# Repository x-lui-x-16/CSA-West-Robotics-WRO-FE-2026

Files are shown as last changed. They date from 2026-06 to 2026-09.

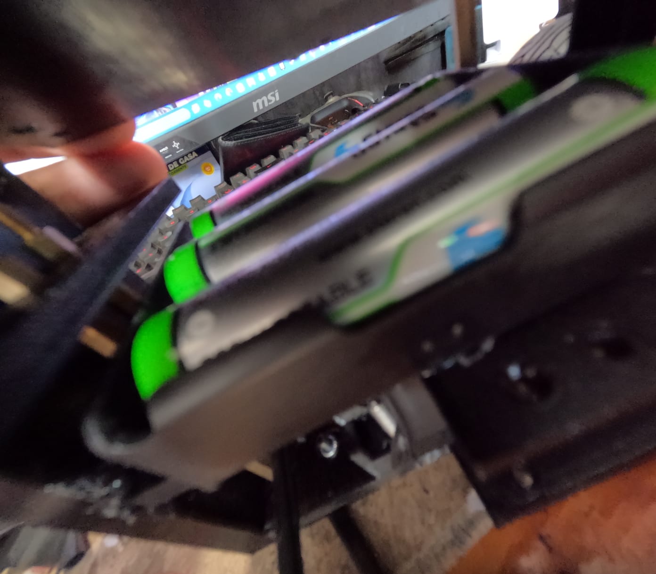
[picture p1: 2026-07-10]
electromechanical-components/battery/battery pic 3.jpeg

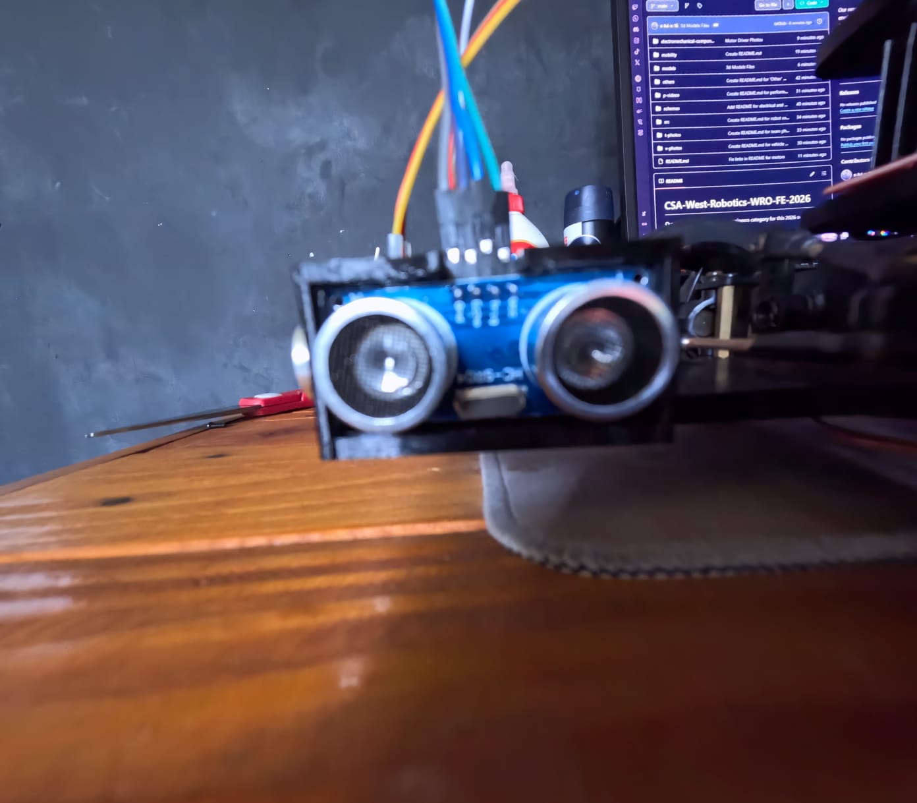
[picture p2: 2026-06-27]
electromechanical-components/ultrasonic-sensors/ultrasonic sensors pic 2.jpeg

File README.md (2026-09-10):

## 👋 Introduction
For the WRO Future Engineers challenge, we built an autonomous robot that combines computer vision, distance sensing, and precise motion control. A **Pixy2 camera** detects colored markers along the track: green means turn left, red means turn right. Three **HC-SR04 ultrasonic sensors** on the front give the robot environmental awareness, letting it detect the front wall and nearby obstacles. Together, vision and ultrasonic sensing let the robot follow navigation rules while avoiding collisions, reliably and adaptively.

## 👥 Our Team
<center>27fb941c-3ae1-49fe-bac8-5fe324d17b53</center>

| Photo | Name | Role - Decription |
|:---:|---|---|
| WhatsApp Image 2026-09-08 at 9 08 41 AM | Ernesto Victoria | Coach - 	Guides the team's strategy, training and overall project direction. |
| WhatsApp Image 2026-08-29 at 6 13 13 PM | Zaory Puga | Programmer - 	Develops and refines the robot's navigation and control code. |
| WhatsApp Image 2026-08-29 at 6 13 14 PM | Dereck Cisneros | Mechanic - 	Designs and builds the robot's chassis and mechanical systems. |
| WhatsApp Image 2026-08-29 at 6 13 13 PM (1) | Luis Hidalgo | Mechanic & Programmer — Team Captain - Leads the team, combining mechanical design with programming to integrate the robot's systems. |

## 🛠️ Building Instructions
- Chassis: mostly 3D-printed, with some supports from the [YFROBOT Kit Chassis](https://yfrobot.com/products/steering-gear-robot).
- 3D Models: [printable STL files](models/)
- Electronics: [circuit diagrams](schemes/)
- Code: [Arduino source code](src/)

## 🚗 Mobility
Our robot uses **Ackermann steering**, the same geometry found in real cars, steering only the front wheels while the rear wheels drive. An **MG996R servo** actuates the steering linkage based on decisions from the **Arduino Mega 2560 R3**. Propulsion comes from a **LEGO EV3 Large Motor** on a rigid rear axle. This separation of steering and driving reduces wheel slip, improves traction, and gives smoother, more predictable handling — important for accurate obstacle avoidance and parking.
- [RWD System](mobility/rwd-system/) · [Steering Mechanism](mobility/steering-mechanism/)

## 🎯 Strategy
- **Color detection:** the Pixy2 cam identifies green/red markers; green → turn left, right → turn right.
- **Turn triggering:** the robot drives straight until the front sensor detects the wall is close; side sensors then decide turn direction.
- **Color algorithm & obstacle-avoidance routine:** to be documented in phase 2.

## 💻 Code Overview
The robot: waits for a start button → drives forward with the steering servo held straight (90°), with no wall-following correction → watches the front sensor to detect the front wall → checks side distances to decide turn direction → executes a timed 90° turn via the servo → counts turns → repeats until the required laps are done → makes a final short move and stops.

**Key logic:**
- A simple **state machine** (`DRIVE_STRAIGHT`, `TURNING_LEFT`, `TURNING_RIGHT`, `FINISHED`) organizes behavior.
- The robot drives straight until the front sensor reads a distance below `FRONT_TURN_TRIGGER_MM`, signaling that the front wall is close.
- Turns are currently **time-based** (`turn90TimeMs`), which is simple but can vary with battery level, traction, and surface — a future version could add wheel encoders or an IMU for more precise turning.
- Tunable parameters: servo angles, `baseSpeedPercent`, `turnSpeedPercent`, `turn90TimeMs`, `FRONT_TURN_TRIGGER_MM`, `TURN_RATIO`, final-stop timing.

## ⚙️ Electromechanical Components
- **Power:** 3S 18650 Li-ion battery pack (three 3.7V, 2800 mAh 18650 cells in series) → L298N (+12V/GND) → onboard 5V regulator powers a breadboard distributing to Arduino, sensors, etc. Includes a power switch and a start button.
- **Controller:** Arduino Mega 2560 R3 — processes sensor data and controls the motors.
- **Vision:** Pixy2 Camera detects red/green markers and reports to the Arduino for turn decisions. *(Communication protocol & detection algorithm to be documented in phase 2.)*
- **Ultrasonic sensors:** 3× HC-SR04 (left, center, right), ~2–400 cm range, ~3 mm accuracy — used for obstacle detection and front-wall detection.
- **Drive:** LEGO EV3 Large Motor, with a built-in rotation sensor.
- **Steering:** MG996R digital servo (4.8–7.2V, PWM control).
- **Motor driver:** L298N Dual H-Bridge — also supplies regulated 5V.
- **Chassis:** custom-designed, mostly 3D-printed (4 wheels, 8 supports, mounting screws), optimizing component placement and easy maintenance.

### 🔋 Power System
The robot is powered by a 3-cell (3S) 18650 lithium battery pack, which supplies the energy required for all electronic and mechanical components. The battery holder includes an integrated power switch, allowing the entire robot to be turned on safely before each run.

The battery pack is connected directly to the L298N motor driver through its +12V and GND terminals. The onboard 5V regulator of the L298N is then used to power a breadboard, which distributes power to the Arduino, sensors, and the remaining electronic devices.

To improve usability during competitions, the robot also includes a push button that starts the autonomous program after the robot has been powered on.

[📷 Power System Image](electromechanical-components/battery/)

### 🧠 Main Controller

The main controller of the robot is an Arduino Mega 2560 R3, which acts as the central processing unit of the entire system. It receives information from the vision system and ultrasonic sensors, processes all navigation decisions, and controls the motors accordingly.

Its compact size, processing capability, and reliable I/O communication make it an excellent choice for autonomous robotics applications.

[📷 Arduino Mega 2560 R3 Image](electromechanical-components/arduino/)

### 👁️ Vision System

The robot uses a Pixy2 Camera to detect the colored obstacle markers placed around the track.

A custom vision algorithm allows the camera to distinguish between red and green objects. Once a color is identified, the corresponding information is transmitted to the Arduino Mega 2560 R3, which decides whether the robot should turn left or right according to the competition rules.

#### Communication Protocol:

The communication protocol will be developed and documented in the second phase of the challenge.  

This section will later describe how the robot exchanges information between the arduino and the Pixy2 Camera, the structure of the transmitted data, and how that communication supports the overall project workflow.

#### Detection Algorithm:

The detection algorithm will also be addressed in the second phase of the challenge.  

At that stage, this section will explain how camera data is processed to identify relevant conditions, events, or targets, and how those detections are integrated into the robot’s navigation and decision-making logic.

[📷 Pixy2 Camera Image](electromechanical-components/pixy2/)

### 📏 Ultrasonic Sensors

Three HC-SR04 ultrasonic sensors are mounted across the front of the robot.

These sensors continuously measure the distance between the robot and nearby walls or obstacles, allowing the robot to navigate safely through the track.

Each HC-SR04 sensor provides non-contact distance measurements from approximately 2 cm to 400 cm, with an accuracy of up to 3 mm.

The sensor arrangement consists of:
- Left ultrasonic sensor
- Center ultrasonic sensor
- Right ultrasonic sensor

Together, these sensors provide the robot with a wider field of view, enabling more accurate obstacle avoidance and wall-following behavior.

[📷 Ultrasonic Sensors](electromechanical-components/ultrasonic-sensors/)

### ⚙️ Drive System

#### DC Motor

The robot is driven by the EV3 Large Motor.

These motors provide a good balance between speed and torque, allowing smooth movement while maintaining enough power for acceleration, turning, and obstacle avoidance during the competition.

[📷 DC Motor](electromechanical-components/motors/dc-motor/)

#### Servo Motor

The robot uses an MG996R high-torque servo motor to control the steering mechanism of the front wheels. Unlike differential-drive robots, our vehicle follows an Ackermann-inspired steering configuration, allowing it to perform smoother and more realistic turns while maintaining stability throughout the course.

The Arduino Mega 2560 R3 continuously calculates the desired steering angle using data from the Pixy2 camera and the ultrasonic sensors. Based on this information, the servo precisely adjusts the front wheels, enabling the robot to navigate around obstacles, follow the track, and execute accurate parking maneuvers.

The MG996R was selected because of its high torque, fast response, and reliable performance, making it well suited for the steering demands of the WRO Future Engineers challenge.

Specifications:
- Model: MG996R
- Operating Voltage: 4.8–7.2 V
- Control Signal: PWM
- Type: High-Torque Digital Servo

[📷 Servo Motor](electromechanical-components/motors/servo-motor/)

### 🎮 Motor Driver

Motor control is performed using an L298N Dual H-Bridge Motor Driver.

The driver receives movement commands from the Arduino Mega 2560 R3 and regulates the motors accordingly. Besides driving the motors, the L298N also provides a regulated 5V output, which is used to power the breadboard and the robot's low-voltage electronics.

The L298N was selected because it is reliable, easy to integrate, and widely used in educational and robotics projects.

[📷 Motor Driver](electromechanical-components/motor-driver/)

### 🏗️ Mechanical Structure

The chassis was entirely designed by our team and manufactured primarily using 3D printing.

Almost every structural component of the robot is custom-made, allowing us to optimize the placement of electronics, reduce weight, simplify maintenance, and adapt the robot specifically for the WRO Future Engineers challenge.

Only the structural supports and steering mechanism were not 3D printed.

The robot includes:
- 4 wheels
- 8 structural supports
- Structural mounting screws
- Custom 3D-printed chassis

This modular design allows individual components to be replaced quickly without rebuilding the entire robot.

### 🔌 Wiring Diagram

The electrical connections between all components are summarized in the wiring diagram below.
FE-2026 V3 Wiring Diagram
### 📸 Component Gallery

The following folder shows images of all the main electromechanical components used in the robot.
- [Electromechanical Components](electromechanical-components/)
📸 [Component gallery](electromechanical-components/)

## ⚡ Power Management

The robot is powered by a **3S 18650 lithium battery pack** pack (three 3.7V, 2800 mAh cells in series), which supplies the main power source for the entire system. The battery output is connected directly to the **L298N motor driver** through its **+12V** and **GND** terminals. This allows the driver to power the DC motors while simultaneously providing a regulated **5V output**.

The regulated **5V** and **GND** outputs from the L298N are connected to a **breadboard**, which acts as the central power distribution point for the low-voltage electronics. From there, power is supplied to the **Arduino Mega 2560 R3**, the **Pixy2 camera**, the **MG996R steering servo**, and the **HC-SR04 ultrasonic sensors**.

To improve safety and usability, the robot includes a **main power switch** that disconnects the battery from the entire electrical system when not in use. Additionally, a dedicated **start button** allows the robot to remain powered while delaying the execution of the autonomous program until the official start signal is given.

This power management architecture simplifies wiring, centralizes power distribution, and ensures that all electronic components receive a stable supply voltage throughout the robot's operation.

## 🫶🏽 Acknowledgements
- **Colegio San Agustín La Chorrera** — guidance and workspace.
- **Gabriel Rodríguez (Banistmo)** — technical guidance, programming support and feedback.
- **TekBot Lab** — help with robot design and technical feedback.

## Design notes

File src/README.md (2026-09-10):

# 💻 Source Code
This directory contains all the software developed for the robot.

The code is written for the Arduino Mega 2560 R3 and manages all the robot's autonomous behavior, including sensor processing, decision-making, and motor control.

## 📌 Features
- Real-time sensor data processing
- Color detection integration (Pixy2 camera)
- Obstacle detection using ultrasonic sensors
- Steering control using servo motor
- Motor control via L298N driver
- Autonomous navigation logic

## ⚙️ System Behavior
The robot continuously reads sensor inputs, processes environmental data, and executes movement decisions in real time to complete the WRO challenge autonomously.

## 🧠 Architecture
The software is structured to ensure modularity, making it easier to test, debug, and improve individual subsystems.

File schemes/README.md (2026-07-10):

# 🗺️ Schemes
This directory contains all electrical and wiring diagrams used in the robot.

These schemes document how each component is connected, ensuring clarity in the system architecture and facilitating debugging, assembly, and maintenance.

## 📌 Contents
- Wiring diagrams of the robot
- Wiring Explanation detailed

## ⚡ Overview
The diagrams illustrate how power and data flow between the Arduino Nano 33 IoT, Pixy2 camera, ultrasonic sensors, motor driver, and steering system.

These schematics are essential for understanding the robot’s electrical design.

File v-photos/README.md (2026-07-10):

# 🤖🚗 Vehicle Photos
This directory contains detailed images of the robot.

## 📌 Contents
- Full robot assembly photos
- Front, side, and top views

## 🔍 Purpose
These images help illustrate the mechanical design, component layout, and overall structure of the robot, providing a clear understanding of the system architecture.

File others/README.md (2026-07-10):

# 📁 Other
This folder contains miscellaneous files related to the project.

At the moment, this directory is kept empty or used for temporary files that are not part of the main system structure.

## 📌 Purpose
This space is reserved for:
- Experimental files
- Backup resources
- Temporary documentation
- Non-critical assets

## 🧹 Status
Currently, no essential files are stored in this directory.

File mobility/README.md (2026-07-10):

# 🚗 Mobility
This section shows the robot’s mobility system and steers.

The robot is designed with a separated propulsion and steering architecture to ensure smooth and precise movement throughout the WRO Future Engineers challenge.

## 📌 Contents
- Ackermann steering system
- Rear-wheel drive configuration

## ⚙️ System Overview
The robot uses a **rear-wheel drive system** powered by a Geartisan 12V DC motor, which provides consistent forward motion.

Steering is handled by an **MG996R servo motor**, which controls an Ackermann-style linkage connected to the front wheels. This setup allows for smooth turning behavior and reduces wheel slip during direction changes.

The combination of these two systems ensures stable navigation, accurate turning radius control, and reliable performance in dynamic track conditions.

## 🔍 Purpose
The mobility system is designed to replicate realistic vehicle behavior, improving stability and control while allowing the robot to execute precise maneuvers such as obstacle avoidance and parking.

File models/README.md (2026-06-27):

# 🧊 Models
This directory contains all the 3D models used in the robot.

All files stored here correspond to parts designed for 3D printing and assembly of the robot structure. These models were created specifically for this project to ensure proper fit, modularity, and mechanical efficiency.

## 📌 Contents
- 3D printable robot parts
- Sensor and electronics mounts

## 🛠️ Purpose
The main purpose of these models is to provide a complete and modular mechanical structure for the robot, allowing easy assembly, replacement, and improvement of components during development and testing.

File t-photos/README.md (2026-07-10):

# 📸 Team Photos
This directory contains the official team photographs for the WRO Future Engineers competition.

## 📌 Contents
- Official team presentation photos
- Group photos of team members
- Competition preparation images

## 🏆 Purpose
These images are used for documentation and team identification during the competition and in the official GitHub repository.

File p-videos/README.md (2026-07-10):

# 📹 Performance Videos
This directory contains videos of the robot performing in different competition scenarios.

## 📌 Contents
- Autonomous navigation tests
- Obstacle detection demonstrations
- Full challenge runs
- System validation recordings

## 🎯 Purpose
These videos demonstrate the robot’s performance, reliability, and ability to complete the required tasks under competition conditions.

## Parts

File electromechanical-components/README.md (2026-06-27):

# ⚙️ Electromechanical Components
This directory contains all the main mechanical and electronic components used in the robot.

## 📌 Contents
- 🔋 Power system 
- 🧠 Main controller 
- 👁️ Vision system 
- 📏 Ultrasonic sensors 
- ⚙️ Drive system 
- 🎮 Motor driver 

## 🔍 Purpose
These components form the complete electromechanical architecture of the robot, integrating power, control, sensing, and actuation systems into a single autonomous platform.

This folder helps document the hardware design and provides a clear overview of how each subsystem contributes to the robot’s overall functionality in the WRO Future Engineers challenge.

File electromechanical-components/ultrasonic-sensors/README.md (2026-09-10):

# 📏 Ultrasonic Sensors (HC-SR04)
Three HC-SR04 ultrasonic sensors are mounted on the front of the robot: left, center, and right. Each one measures distance in a range of roughly 2–400 cm with about 3 mm accuracy.

The center sensor detects when the robot is approaching the front wall, triggering a turn, while the left and right sensors are compared to decide the turn direction.

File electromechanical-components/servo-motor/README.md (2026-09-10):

# 🕹️ Steering Servo (MG996R)
The MG996R is a high-torque digital servo that controls the robot's Ackermann steering mechanism. Based on distance readings and navigation decisions from the Arduino, it adjusts the angle of the front wheels to keep the robot on track and execute turns.

It operates at 4.8–7.2V and is controlled via a standard PWM signal from the Arduino.

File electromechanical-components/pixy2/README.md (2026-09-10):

# 👁️ Pixy2 Camera
The Pixy2 Camera is the robot's vision system. It detects colored markers placed along the track and identifies whether they are green or red. This information is sent to the Arduino, which decides whether the robot should turn left (green) or right (red).

The communication protocol and detection algorithm will be documented in more detail in the next development phase.

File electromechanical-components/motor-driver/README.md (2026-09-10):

# 🎮 Motor Driver (L298N)
The L298N Dual H-Bridge Motor Driver receives movement commands from the Arduino and controls the drive motor's speed and direction. It also provides a regulated 5V output, which powers the breadboard and the robot's low-voltage electronics (Arduino, sensors, servo).

It was selected for being reliable, easy to wire, and widely supported in educational robotics projects.

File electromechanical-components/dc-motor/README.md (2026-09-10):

# ⚙️ Drive Motor
Propulsion is provided by a LEGO EV3 Large Motor, connected to the rigid rear axle. It includes a built-in rotation sensor, which could be used in future versions to measure distance traveled more precisely than the current time-based approach.

This motor was chosen for its reliable torque and smooth speed control, providing consistent forward motion throughout the track.

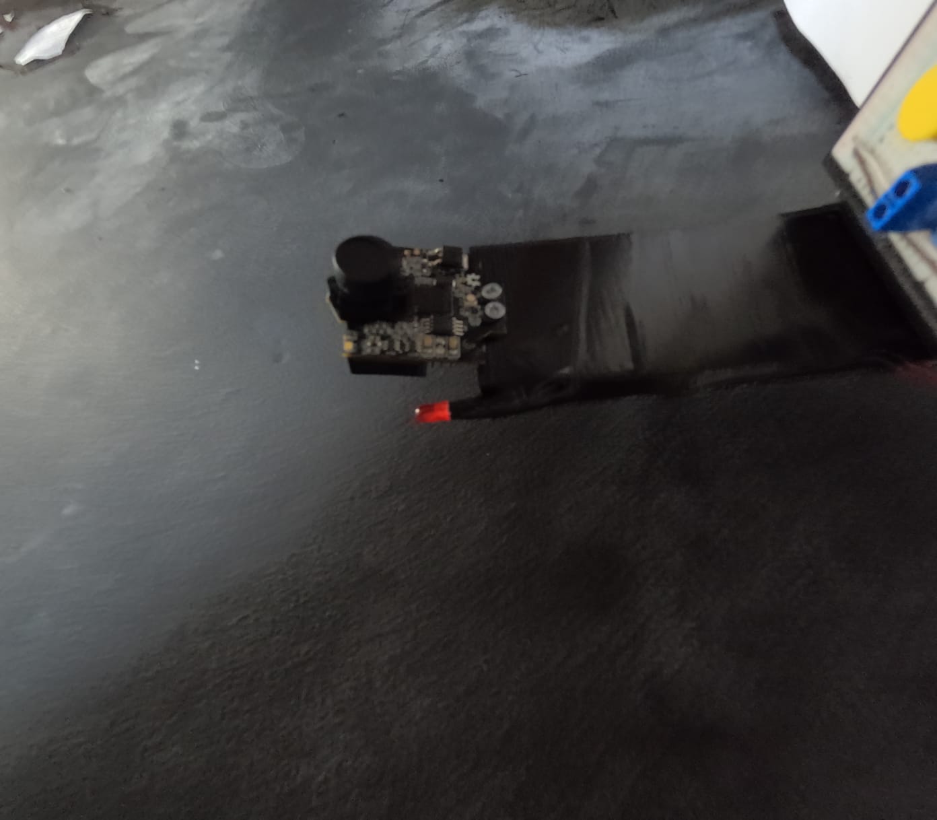
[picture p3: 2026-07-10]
electromechanical-components/pixy2/pixy2 pic 1.jpeg

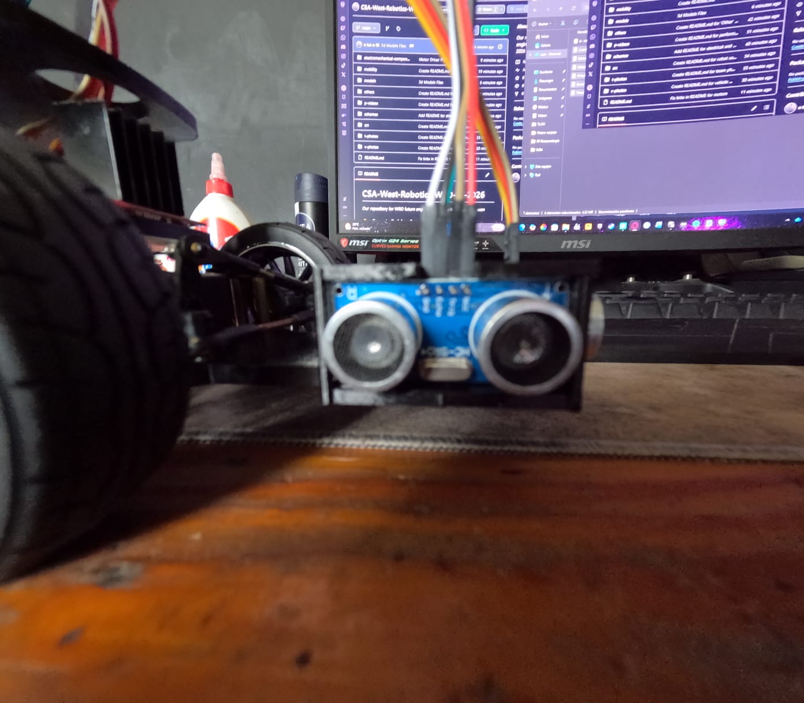
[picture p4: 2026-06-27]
electromechanical-components/ultrasonic-sensors/ultrasonic sensors pic 3.jpeg

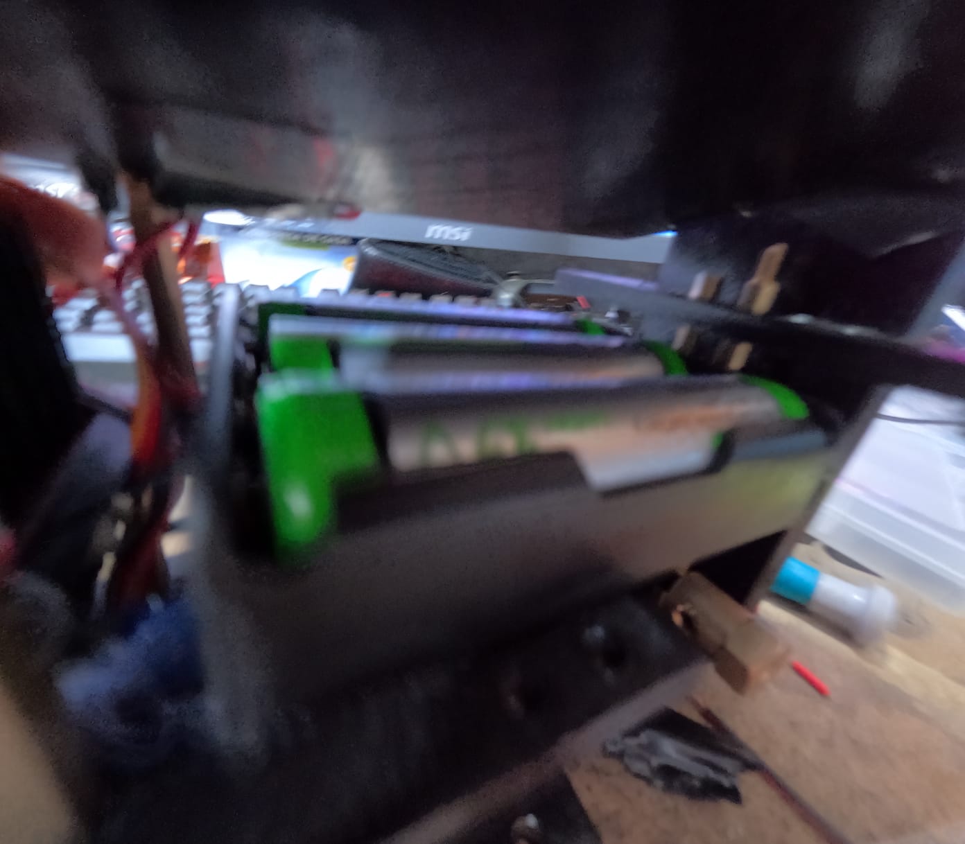
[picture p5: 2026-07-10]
electromechanical-components/battery/battery pic 2.jpeg

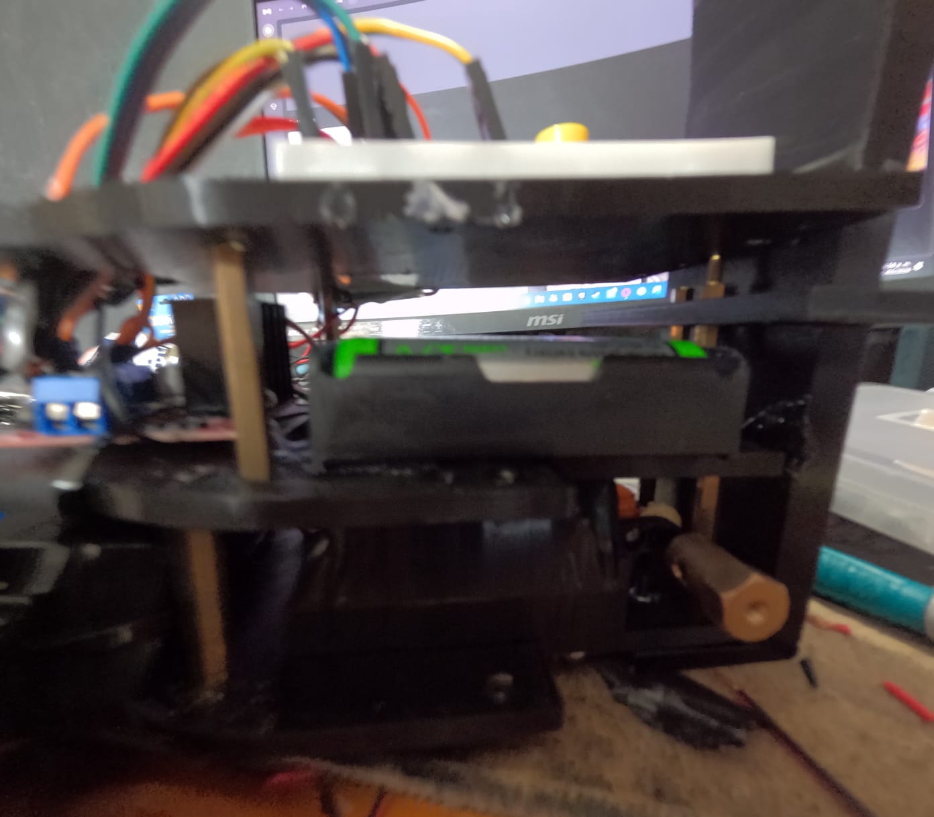
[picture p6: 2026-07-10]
electromechanical-components/battery/battery pic 1.jpeg

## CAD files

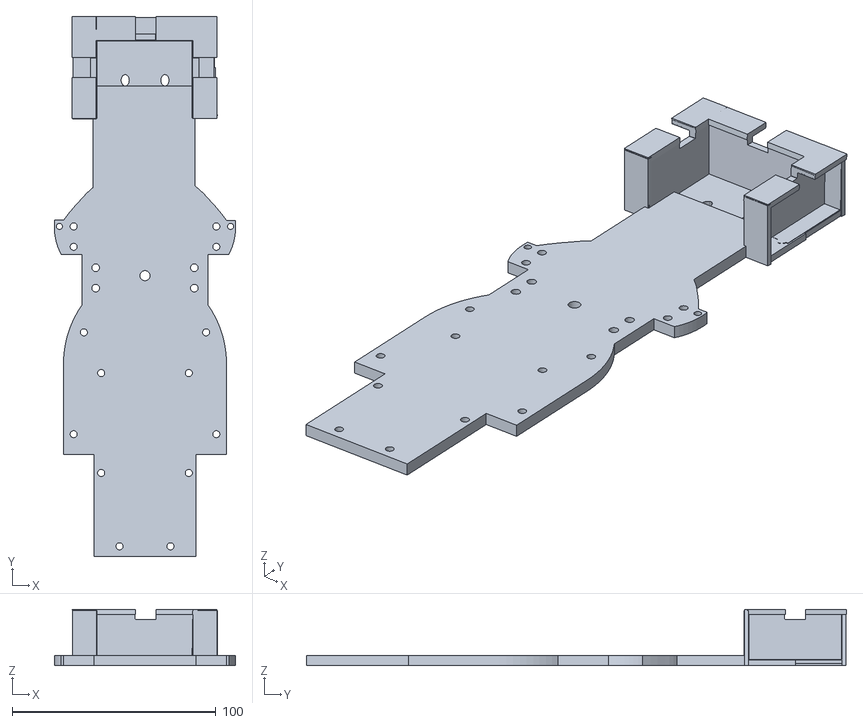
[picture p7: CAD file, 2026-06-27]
models/Principal Base.stl
89.0 x 265.0 x 27.5

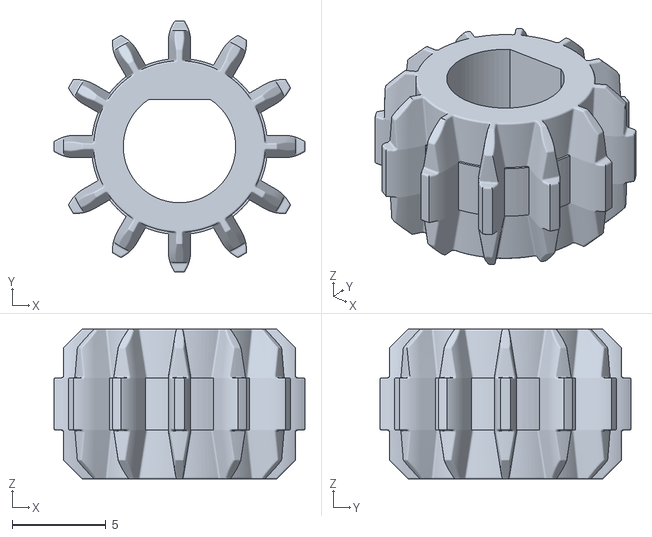
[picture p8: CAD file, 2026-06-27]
models/Motor gear.stl
13.4 x 13.4 x 8.00

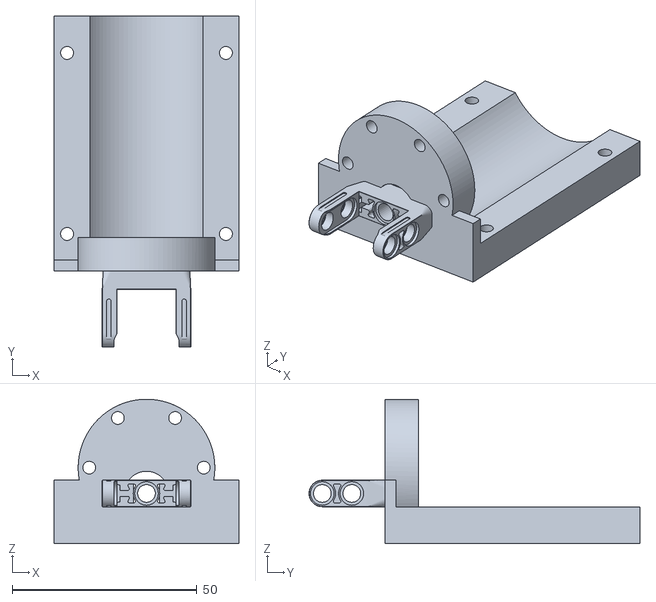
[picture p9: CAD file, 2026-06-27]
models/Motor Mount.stl
50.0 x 89.6 x 39.1

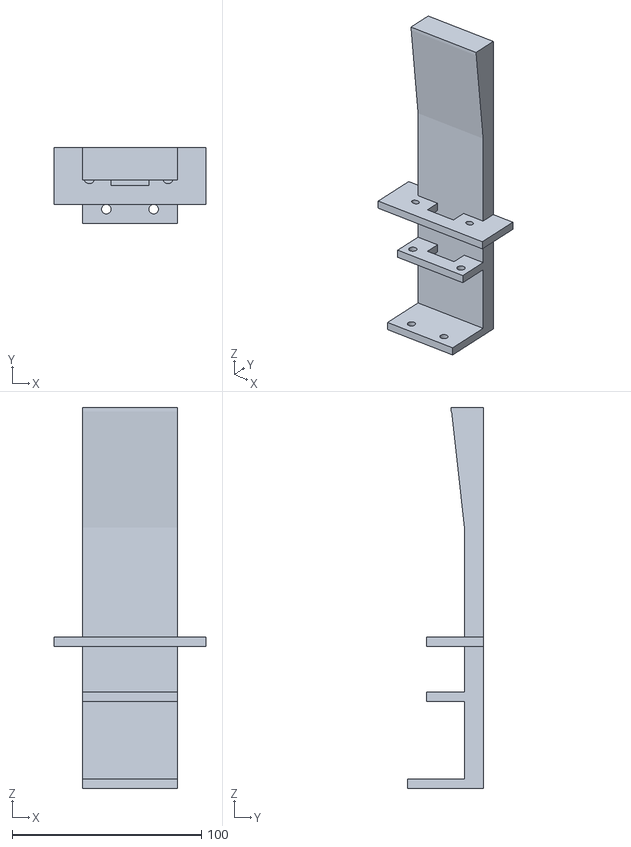
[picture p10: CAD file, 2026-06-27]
models/Camera mount.stl
80.0 x 40.0 x 201.1

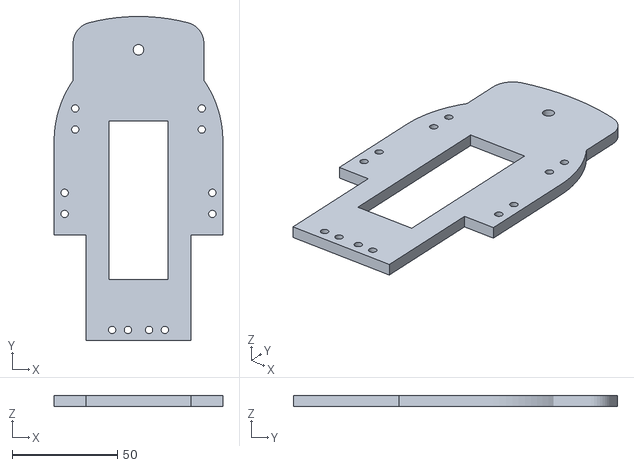
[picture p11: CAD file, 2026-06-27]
models/Second floor base.stl
80.0 x 153.6 x 5.00

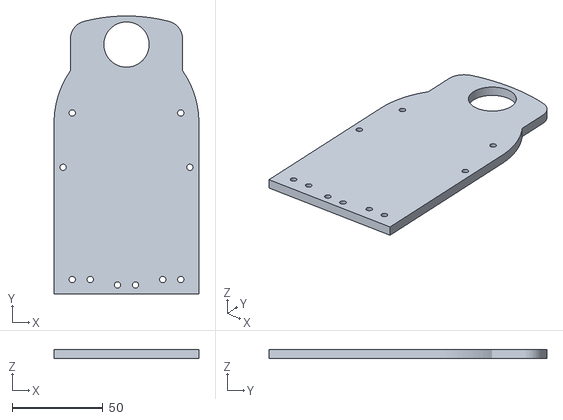
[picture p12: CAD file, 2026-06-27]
models/Third floor base.stl
80.0 x 153.6 x 5.00

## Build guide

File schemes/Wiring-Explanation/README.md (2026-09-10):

## Hardware Architecture
The robot is built around an **Arduino Mega 2560 R3** as the main controller and follows a **rear-wheel-drive configuration with Ackermann steering**.  
Forward motion is provided by a **LEGO EV3 Large Motor** driven through an **L298N motor driver**, while steering is controlled by an **MG996R servo motor** mounted on the front axle.  
Three **HC-SR04 ultrasonic sensors** are used to measure distances to the front, left, and right sides of the robot, allowing it to navigate corridors and evaluate turns.  
The prototype also includes a **start push button**, a **power indicator LED**, and a **main on/off switch** integrated into the battery supply line.

At the current stage of development, the robot is powered by a **3-cell (3S) 18650 battery pack**, with the **L298N motor driver acting as the main power entry point**.  
Low-voltage devices such as the Arduino, ultrasonic sensors, servo, and LED are supplied through the **5V rail distributed from the L298N regulator to the breadboard**.

---

## Power Distribution
The robot uses **three 18650 lithium-ion cells** arranged as a **3-cell series battery pack**.  
This battery pack supplies the motor driver directly and, through the L298N's onboard regulator, also powers the low-voltage electronics.

### Battery configuration
- **Battery type:** 18650 Li-ion
- **Number of cells:** 3
- **Nominal voltage per cell:** 3.7 V
- **Fully charged voltage per cell:** ~4.1 V
- **Total pack voltage:** approximately **11.1 V to 12.3 V**
- **Capacity per cell:** 2800 mAh

### Main power path
```text
Battery Pack (+) → On/Off Switch → L298N +12V
Battery Pack (-) → L298N GND
```
### Low-voltage distribution
The 5V output of the L298N is routed to the breadboard power rail, which then powers the rest of the low-voltage components.
```text
L298N 5V → Breadboard 5V rail
L298N GND → Breadboard GND rail
```
From the breadboard rails, power is distributed to:
- Arduino Mega 2560
- MG996R steering servo
- Front HC-SR04 ultrasonic sensor
- Left HC-SR04 ultrasonic sensor
- Right HC-SR04 ultrasonic sensor
- Power indicator LED

## Wiring Overview
This section describes the robot's wiring as a functional connection diagram in text form, showing how power and signals flow between the main components.
### Global power flow
```text
3x 18650 Battery Pack (+)
        ↓
     On/Off Switch
        ↓
   L298N +12V terminal

3x 18650 Battery Pack (-)
        ↓
    L298N GND
```
The L298N then performs two main tasks:
- Drives the rear drive motor through its output terminals.
- Supplies 5V to the breadboard rail, which powers the Arduino and the rest of the low-voltage electronics.

## Arduino Mega 2560 Connections
The Arduino Mega 2560 acts as the central controller of the robot.
It receives sensor data, reads the start button, controls the rear drive motor through the L298N, and commands the steering servo.
### Arduino pin usage
```text
Arduino Mega 2560
│
├── D2  → MG996R Servo signal
├── D3  → L298N IN2
├── D4  → L298N IN1
├── D5  → L298N ENA
├── D7  → Start Push Button
├── D8  → Front HC-SR04 TRIG
├── D9  → Front HC-SR04 ECHO
├── D10 → Left HC-SR04 TRIG
├── D11 → Left HC-SR04 ECHO
├── D12 → Right HC-SR04 TRIG
├── D13 → Right HC-SR04 ECHO
├── 5V  → Breadboard 5V rail
└── GND → Breadboard GND rail
```
## Rear Drive System
The robot uses a single LEGO EV3 Large Motor for propulsion.
This motor is not connected directly to the Arduino. Instead, it is controlled through one channel of the L298N motor driver.

Control signal path
```text
Arduino D5  → L298N ENA
Arduino D4  → L298N IN1
Arduino D3  → L298N IN2
```
- ENA controls motor speed through PWM.
- IN1 and IN2 control the rotation direction of the motor.
Rear motor output path
```text
L298N OUT1 → Rear Motor terminal 1
L298N OUT2 → Rear Motor terminal 2
```
## Steering System
The front steering mechanism is controlled by an MG996R servo motor connected to the Arduino.
### Servo wiring
```text
Arduino D2         → Servo signal
Breadboard 5V rail → Servo VCC
Breadboard GND rail→ Servo GND
```
The servo is responsible for positioning the front wheels according to the Ackermann steering logic of the robot.

## Ultrasonic Sensing System
The robot uses three HC-SR04 ultrasonic sensors to measure distances in front of the robot and on both sides of the chassis.
### Front ultrasonic sensor
```text
Front HC-SR04 VCC  → Breadboard 5V rail
Front HC-SR04 GND  → Breadboard GND rail
Front HC-SR04 TRIG → Arduino D8
Front HC-SR04 ECHO → Arduino D9
```
The front sensor is used to detect the end of a straight path or the presence of a wall ahead.
### Left ultrasonic sensor
```text
Left HC-SR04 VCC  → Breadboard 5V rail
Left HC-SR04 GND  → Breadboard GND rail
Left HC-SR04 TRIG → Arduino D10
Left HC-SR04 ECHO → Arduino D11
```
The left sensor measures the distance between the robot and the left wall and is used to help decide the turn direction.
### Right ultrasonic sensor
```text
Right HC-SR04 VCC  → Breadboard 5V rail
Right HC-SR04 GND  → Breadboard GND rail
Right HC-SR04 TRIG → Arduino D12
Right HC-SR04 ECHO → Arduino D13
```
The right sensor measures the distance between the robot and the right wall and works together with the left sensor to decide which way to turn.

## Start Button and User Input
The robot includes a push button that is used to manually start the program.
### Button wiring
```text
Arduino D7 → One side of push button
Arduino GND → Other side of push button
```
The code uses INPUT_PULLUP, which means:
- the pin remains HIGH when the button is not pressed,
- the pin becomes LOW when the button is pressed and connected to ground.
This allows the robot to remain idle until the user explicitly starts the routine.

## Power Indicator LED
A red LED is connected as a power indicator to show when the 5V system is active.
### LED wiring
```text
Breadboard 5V rail → 1 kΩ resistor → LED anode (+)
LED cathode (-) → Breadboard GND rail
```
Whenever the breadboard 5V rail is powered, the LED turns on and indicates that the low-voltage electronics are energized.

## Connection Tables
### Arduino Mega 2560 Pin Map
| Arduino Pin | Connected Component | Function |
| --- | --- | --- |
| D2 | MG996R Servo Signal | Steering control |
| D3 | L298N IN2 | Rear motor direction control |
| D4 | L298N IN1 | Rear motor direction control |
| D5 | L298N ENA | Rear motor PWM speed control |
| D7 | Push Button | Manual program start |
| D8 | Front HC-SR04 TRIG | Front distance trigger |
| D9 | Front HC-SR04 ECHO | Front distance echo |
| D10 | Left HC-SR04 TRIG | Left distance trigger |
| D11 | Left HC-SR04 ECHO | Left distance echo |
| D12 | Right HC-SR04 TRIG | Right distance trigger |
| D13 | Right HC-SR04 ECHO | Right distance echo |

### L298N Motor Driver Connections
| L298N Pin | Connected To | Purpose |
| --- | --- | --- |
| ENA | Arduino D5 | Rear motor PWM speed control |
| IN1 | Arduino D4 | Rear motor direction control |
| IN2 | Arduino D3 | Rear motor direction control |
| OUT1 | Rear Motor Terminal 1 | Motor output |
| OUT2 | Rear Motor Terminal 2 | Motor output |
| +12V | Battery Pack Positive Through Switch | Main motor supply |
| GND | Battery Negative / Breadboard Ground | Common ground |
| +5V | Breadboard 5V Rail | Low-Voltage power distribution |

### Ultrasonic Sensor Conections
| Sensor | Pin | Connected to |
| --- | --- | --- |
| Front HC-SR04 | TRIG | Arduino D8 |
| Front HC-SR04 | ECHO | Arduino D9 |
| Front HC-SR04 | VCC | 5V breadboard rail |
| Front HC-SR04 | GND | GND breadboard rail |
| Left HC-SR04 | TRIG | Arduino D10 |
| Left HC-SR04 | ECHO | Arduino D11 |
| Left HC-SR04 | VCC | 5V breadboard rail |
| Left HC-SR04 | GND | GND breadboard rail |
| Right HC-SR04 | TRIG | Arduino D12 |
| Right HC-SR04 | ECHO | Arduino D13 |
| Right HC-SR04 | VCC | 5V breadboard rail |
| Right HC-SR04 | GND | GND breadboard rail |

### Additional Components
| Component | Connection |
| --- | --- |
| MG996R Servo Signal | Arduino D2 |
| MG996R Servo VCC | 5V breadboard rail |
| MG996R Servo GND | GND breadboard rail |
| Push Button | Arduino D7 and GND |
| Red Power Indicator LED | 5V rail → 1 kΩ resistor → LED → GND  |
| On/Off Switch | In series between battery positive and L298N +12V pin |

## Common Ground Architecture
A common ground is essential for correct operation.
The following grounds are electrically connected together:
- Battery negative terminal
- L298N GND
- Arduino GND
- Servo GND
- Front ultrasonic sensor GND
- Left ultrasonic sensor GND
- Right ultrasonic sensor GND
- LED GND
- Push button ground
Without a common ground reference, the control signals from the Arduino may not be interpreted correctly by the motor driver, servo, or sensors.

## Electrical Design Notes
1. Rear motor connection
The rear drive motor must be connected to the OUT1 and OUT2 terminals of the L298N.
It should not be connected directly to the Arduino or to the control pins IN1 and IN2.
2. Servo power considerations
The MG996R servo can draw a significant amount of current, especially under load.
In the current prototype, it is powered from the same 5V rail used by the Arduino and ultrasonic sensors, with that rail being supplied by the L298N regulator.

This configuration is acceptable for a prototype, but for a more robust version of the robot, a dedicated 5V regulator or separate high-current 5V supply for the servo would be recommended.
3. L298N regulator limitations
The onboard 5V regulator of the L298N is convenient for small loads, but it is not ideal for powering multiple current-demanding devices simultaneously.
Because this robot powers the Arduino, the servo, the ultrasonic sensors, and the LED from the same 5V source, the power system should be monitored under load.
4. Common symptoms of power instability
If the robot shows any of the following symptoms:
- Arduino resets,
- servo jitter,
- unstable ultrasonic readings,
- reduced motor performance,
the first subsystem that should be checked is the power distribution stage.

## Prototype Scope
This wiring description corresponds to the current prototype stage of the robot.
Additional components such as the Pixy2 camera, communication interfaces, or other sensing modules may be integrated in future development phases and documented in updated hardware and wiring sections.

## Hardware Summary
- **Main controller:** Arduino Mega 2560 R3  
- **Drive motor:** LEGO EV3 Large Motor  
- **Steering actuator:** MG996R servo  
- **Motor driver:** L298N  
- **Distance sensors:** 3 × HC-SR04 ultrasonic sensors  
- **User controls:** Push button + on/off switch  
- **Power indicator:** Red LED with 1 kΩ resistor  
- **Power source:** 3 × 18650 Li-ion cells in series (3.7V, 2800 mAh each)

## Future Hardware Integration
- Pixy2 camera integration
- color detection subsystem
- communication protocol
- extended detection algorithm

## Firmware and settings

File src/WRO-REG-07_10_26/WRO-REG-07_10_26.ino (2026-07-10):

#include <Servo.h>
Servo miServo;

/* =========================================================
   ULTRASONIC SENSOR PINS (HC-SR04)
   ---------------------------------------------------------
   TRIG = pin that sends the ultrasonic pulse
   ECHO = pin that receives the reflected pulse
   ---------------------------------------------------------
   Sensor layout used in this program:
   - TRIG1 / ECHO1 -> Front sensor
   - TRIG2 / ECHO2 -> Left sensor
   - TRIG3 / ECHO3 -> Right sensor
   ========================================================= */
#define TRIG1 8   // Front ultrasonic sensor trigger pin
#define ECHO1 9   // Front ultrasonic sensor echo pin

#define TRIG2 10  // Left ultrasonic sensor trigger pin
#define ECHO2 11  // Left ultrasonic sensor echo pin

#define TRIG3 12  // Right ultrasonic sensor trigger pin
#define ECHO3 13  // Right ultrasonic sensor echo pin


/* =========================================================
   L298N MOTOR DRIVER PINS
   ---------------------------------------------------------
   This code assumes ONE drive motor connected to channel A
   of the L298N module.

   ENA -> PWM speed control pin
   IN1 and IN2 -> direction control pins

   If later change the wiring, only modify these values.
   ========================================================= */
const int ENA = 5;   // PWM pin used to control motor speed
const int IN1 = 4;   // Motor direction pin 1
const int IN2 = 3;   // Motor direction pin 2


/* =========================================================
   SERVO PIN
   ---------------------------------------------------------
   The servo controls the steering system.
   ========================================================= */
const int servoPin = 2;

/* =========================================================
   START BUTTON PIN
   ---------------------------------------------------------
   This push button is used to start the robot manually.

   Wiring used in this code:
   - one side of the button goes to the Arduino pin below
   - the other side of the button goes to GND

   The pin will be configured with INPUT_PULLUP in setup(),
   so the reading works like this:
   - HIGH = button not pressed
   - LOW  = button pressed
   ========================================================= */
const int startButtonPin = 7;

/* =========================================================
   SERVO ANGLES FOR ACKERMANN STEERING
   ---------------------------------------------------------
   These are the steering positions that the robot uses.
   ========================================================= */
const int SERVO_CENTER      = 90;   // Straight ahead
const int SERVO_MAX_LEFT    = 35;   // Max left steering
const int SERVO_MAX_RIGHT   = 155;  // Max right steering


/* =========================================================
   ROBOT / TRACK DIMENSIONS
   ---------------------------------------------------------
   All values are in millimeters unless stated otherwise.

   ROBOT_WIDTH_MM:
   Distance between the left and right ultrasonic sensors.
   The robot width at the sensor line is 85 mm.

   LANE_WIDTH_MM:
   Width of the path the robot must travel through.

   TARGET_SIDE_DISTANCE_MM:
   If the robot is centered, each side sensor should read
   approximately this distance:
      (lane width - robot width) / 2

   SIDE_TOLERANCE_MM:
   Allowed error. The robot does not need to be perfectly centered
   to the millimeter. Around 50-60 mm tolerance.
   ========================================================= */
const float ROBOT_WIDTH_MM = 85.0;
const float LANE_WIDTH_MM  = 1000.0;
const float TARGET_SIDE_DISTANCE_MM = (LANE_WIDTH_MM - ROBOT_WIDTH_MM) / 2.0;  // 457.5 mm
const float SIDE_TOLERANCE_MM = 60.0;  // Allowed centering error


/* =========================================================
   FRONT DETECTION DISTANCE
   ---------------------------------------------------------
   When the front sensor reads a distance lower than or equal to
   this value, the robot will consider that it is approaching the
   end of the current straight corridor and will start evaluating
   a turn.

   980 mm = 98 cm
   ========================================================= */
const float FRONT_TURN_TRIGGER_MM = 980.0;


/* =========================================================
   TURN DECISION LOGIC
   ---------------------------------------------------------
   To decide the turning side, we compare left and right distances.

   Example:
   - turn right if right distance >= left distance * TURN_RATIO
   - turn left  if left distance  >= right distance * TURN_RATIO

   A condition similar to "one side must be at least
   double the other side", so TURN_RATIO = 2.0

   If this condition is not met, the robot will keep moving forward
   a little and keep checking until a clearer turn opening appears.
   ========================================================= */
const float TURN_RATIO = 2.0;


/* =========================================================
   PD CONTROLLER CONSTANTS
   ---------------------------------------------------------
   The robot will try to stay centered by comparing the left and
   right distances.

   Error definition used here:
      error = leftDistance - rightDistance

   Meaning:
   - error > 0  -> left side is more open than right side
                   so the robot is closer to the right wall
   - error < 0  -> right side is more open than left side
                   so the robot is closer to the left wall

   The PD controller converts that error into a steering correction.

   KP controls how strongly the robot reacts to the current error.
   KD controls how strongly the robot reacts to sudden error changes.

   Start with these values, then tune if needed:
   - If the robot reacts too weakly and drifts, increase KP a little.
   - If it oscillates too much left/right, reduce KP or increase KD.
   ========================================================= */
float KP = 0.10;   // Proportional gain
float KD = 0.35;   // Derivative gain


/* =========================================================
   MOTOR SPEED SETTINGS
   ---------------------------------------------------------
   baseSpeedPercent:
   Main forward speed while the robot is driving straight.

   turnSpeedPercent:
   Speed used during the 90-degree turning maneuver.
   It is often safer to turn a bit slower than driving straight.
   ========================================================= */
int baseSpeedPercent = 45;   // 0 to 100
int turnSpeedPercent = 35;   // 0 to 100


/* =========================================================
   TURN TIMING
   ---------------------------------------------------------
   Since there is no encoder or IMU in this code, the 90-degree turn
   is approximated using time while the steering is fully left/right.

   IMPORTANT:
   This value WILL need real-world calibration.
   Example:
   - If the robot turns less than 90°, increase the time.
   - If it turns more than 90°, decrease the time.
   ========================================================= */
unsigned long turn90TimeMs = 1050;   // Adjust after testing


/* =========================================================
   LOOP TIMING / SENSOR UPDATE
   ---------------------------------------------------------
   controlIntervalMs:
   Time between each control update.
   Using a fixed control period helps the PD controller behave
   more consistently.
   ========================================================= */
const unsigned long controlIntervalMs = 50;

/* =========================================================
   TURN COUNTER / LAP COUNTER
   ---------------------------------------------------------
   The track requires 12 turns to complete 3 full laps
   (4 turns per lap x 3 laps = 12 turns).

   totalTurnsNeeded:
   How many 90-degree turns must be completed before stopping.

   completedTurns:
   Counts how many turns the robot has already finished.
   ========================================================= */
const int totalTurnsNeeded = 12;
int completedTurns = 0;

/* =========================================================
   FINAL FORWARD MOVEMENT AFTER THE LAST TURN
   ---------------------------------------------------------
   After completing the 12th turn, the robot will move straight
   for a short extra time so it can stop closer to the same
   position where it originally started.

   finalForwardSpeedPercent:
   Speed used for that final straight movement.

   finalForwardTimeMs:
   How long the robot should keep moving after the 12th turn
   before stopping completely.

   IMPORTANT:
   This value must be calibrated on the real track.
   If the robot stops too early, increase finalForwardTimeMs.
   If it goes too far, decrease finalForwardTimeMs.
   ========================================================= */
int finalForwardSpeedPercent = 35;
unsigned long finalForwardTimeMs = 500;

/* =========================================================
   STATE MACHINE
   ---------------------------------------------------------
   Instead of putting all robot behavior mixed together,
   we use "states". This makes the code easier to understand.

   STATE_DRIVE_CENTER:
      Robot drives forward and uses PD to stay centered.

   STATE_TURNING_LEFT:
      Robot is executing a 90-degree left turn.

   STATE_TURNING_RIGHT:
      Robot is executing a 90-degree right turn.

   STATE_FINISHED:
      Robot stops after completing all required turns.
   ========================================================= */
enum RobotState {
  STATE_DRIVE_CENTER,
  STATE_TURNING_LEFT,
  STATE_TURNING_RIGHT,
  STATE_FINISHED
};

RobotState currentState = STATE_DRIVE_CENTER;

/* =========================================================
   START STATE FLAG
   ---------------------------------------------------------
   This variable tells the program whether the robot is still
   waiting for the start button or if it has already started.

   false -> robot is stopped and waiting for the button
   true  -> robot has already started and can run the normal loop
   ========================================================= */
bool robotStarted = false;

/* =========================================================
   VARIABLES USED BY THE PD CONTROLLER
   ---------------------------------------------------------
   previousError:
   Stores the last error value to compute the derivative term.

   lastControlTime:
   Stores the last time the control loop was executed.
   ========================================================= */
float previousError = 0.0;
unsigned long lastControlTime = 0;


/* =========================================================
   VARIABLES USED BY THE TURNING STATE
   ---------------------------------------------------------
   turnStartTime:
   Stores the exact moment when a turn started.
   Used to know when the programmed 90-degree turn time is over.
   ========================================================= */
unsigned long turnStartTime = 0;


/* =========================================================
   FUNCTION: percentToPWM
   ---------------------------------------------------------
   Converts a speed value from 0-100 (%) into 0-255 (PWM),
   which is what analogWrite() uses on Arduino.
   ========================================================= */
int percentToPWM(int percent) {
  percent = constrain(percent, 0, 100);
  return map(percent, 0, 100, 0, 255);
}


/* =========================================================
   FUNCTION: setMotorForward
   ---------------------------------------------------------
   Drives the motor forward using a speed in percentage.
   ========================================================= */
void setMotorForward(int speedPercent) {
  int pwmValue = percentToPWM(speedPercent);

  digitalWrite(IN1, HIGH);
  digitalWrite(IN2, LOW);
  analogWrite(ENA, pwmValue);
}


/* =========================================================
   FUNCTION: stopMotor
   ---------------------------------------------------------
   Stops the drive motor.
   ========================================================= */
void stopMotor() {
  analogWrite(ENA, 0);
  digitalWrite(IN1, LOW);
  digitalWrite(IN2, LOW);
}


/* =========================================================
   FUNCTION: readDistanceMM
   ---------------------------------------------------------
   Reads distance from one HC-SR04 sensor and returns the value
   in millimeters.

   How it works:
   1) Send a 10 microsecond pulse to TRIG.
   2) The sensor emits ultrasound.
   3) pulseIn() measures how long the echo pin stays HIGH.
   4) That time is converted into distance.

   Return value:
   - distance in millimeters if a valid echo is received
   - -1 if no echo is received within the timeout

   The timeout is set to 30000 us (~5 meters max theoretical range),
   but practical HC-SR04 range is lower.
   ========================================================= */
float readDistanceMM(int trigPin, int echoPin) {
  digitalWrite(trigPin, LOW);
  delayMicroseconds(3);

  digitalWrite(trigPin, HIGH);
  delayMicroseconds(10);
  digitalWrite(trigPin, LOW);

  long duration = pulseIn(echoPin, HIGH, 30000);

  if (duration == 0) {
    return -1;  // No valid reading
  }

  // Distance in cm = duration * 0.0343 / 2
  // Distance in mm = distance in cm * 10
  float distanceMM = (duration * 0.343) / 2.0;

  return distanceMM;
}


/* =========================================================
   FUNCTION: readAllSensors
   ---------------------------------------------------------
   Reads the front, left and right ultrasonic sensors.

   We pass the variables by reference so the function can fill them
   directly and keep the main loop cleaner and easier to read.
   ========================================================= */
void readAllSensors(float &frontMM, float &leftMM, float &rightMM) {
  frontMM = readDistanceMM(TRIG1, ECHO1);
  delay(5);  // small separation between ultrasonic reads to reduce interference

  leftMM = readDistanceMM(TRIG2, ECHO2);
  delay(5);

  rightMM = readDistanceMM(TRIG3, ECHO3);
  delay(5);
}
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
void loop() {
  /* =====================================================
     START BUTTON LOGIC
     -----------------------------------------------------
     The robot will remain stopped until the user presses
     the start button.

     Because the button uses INPUT_PULLUP:
     - button NOT pressed = HIGH
     - button pressed     = LOW
     ===================================================== */
  if (!robotStarted) {
    stopMotor();
    miServo.write(SERVO_CENTER);

    // If the button is pressed, allow the robot to start
    if (digitalRead(startButtonPin) == LOW) {
      delay(30);  // small debounce delay

      // Check again to reduce false triggers from button bounce
      if (digitalRead(startButtonPin) == LOW) {
        robotStarted = true;
        lastControlTime = millis();  // reset control timing reference
        previousError = 0;           // reset PD memory

        Serial.println("START BUTTON PRESSED -> Robot started.");

        // Wait until the button is released so one press does not
        // accidentally trigger extra unwanted behavior
        while (digitalRead(startButtonPin) == LOW) {
          delay(5);
        }
      }
    }

    // While waiting for the button, do nothing else
    return;
  }

  /* =====================================================
     FINISHED STATE
     -----------------------------------------------------
     If the robot already completed all required turns,
     keep it stopped and do nothing else.
     ===================================================== */
  if (currentState == STATE_FINISHED) {
    stopMotor();
    miServo.write(SERVO_CENTER);
    return;
  }

  /* =====================================================
     FIXED CONTROL PERIOD
     -----------------------------------------------------
     The control logic is executed only every
     "controlIntervalMs" milliseconds.
     This helps keep the PD behavior more stable.
     ===================================================== */
  if (millis() - lastControlTime < controlIntervalMs) {
    return;
  }
  lastControlTime = millis();

  /* =====================================================
     SENSOR READING
     -----------------------------------------------------
     Read all three ultrasonic sensors:
     - front
     - left
     - right
     ===================================================== */
  float frontMM, leftMM, rightMM;
  readAllSensors(frontMM, leftMM, rightMM);

  /* =====================================================
     DEBUG PRINTS
     -----------------------------------------------------
     These values are very useful while tuning the robot:
     - front distance
     - left distance
     - right distance
     - number of completed turns
     ===================================================== */
  Serial.print("Front: ");
  Serial.print(frontMM);
  Serial.print(" mm | Left: ");
  Serial.print(leftMM);
  Serial.print(" mm | Right: ");
  Serial.print(rightMM);
  Serial.print(" mm | Turns: ");
  Serial.println(completedTurns);

  switch (currentState) {

    /* ===================================================
       STATE 1: DRIVE CENTERED
       ---------------------------------------------------
       In this state the robot:
       1) moves forward
       2) uses PD to stay centered
       3) checks if it is approaching a corner
       =================================================== */
    case STATE_DRIVE_CENTER: {

      // Drive forward at the normal straight speed
      setMotorForward(baseSpeedPercent);

      // Use left and right sensors to stay centered
      applyPDCentering(leftMM, rightMM);

      /* -------------------------------------------------
         TURN DETECTION
         -------------------------------------------------
         If the front sensor detects the next wall/corner
         at or below the configured trigger distance,
         compare the side distances to decide the turn
         direction.

         Turn right if:
           right side is at least TURN_RATIO times left side

         Turn left if:
           left side is at least TURN_RATIO times right side
         ------------------------------------------------- */
      if (frontMM > 0 && frontMM <= FRONT_TURN_TRIGGER_MM) {

        bool canTurnRight = (rightMM > 0 && leftMM > 0 && rightMM >= leftMM * TURN_RATIO);
        bool canTurnLeft  = (rightMM > 0 && leftMM > 0 && leftMM >= rightMM * TURN_RATIO);

        if (canTurnRight) {
          beginRightTurn();
        }
        else if (canTurnLeft) {
          beginLeftTurn();
        }
        else {
          // No clear turn direction yet.
          // Keep moving centered and continue checking.
          Serial.println("Front trigger detected, but turn side is not clear yet.");
        }
      }

      break;
    }

    /* ===================================================
       STATE 2: TURNING LEFT
       ---------------------------------------------------
       Keep steering fully left and moving forward until
       the programmed turning time is completed.
       =================================================== */
    case STATE_TURNING_LEFT: {
      setMotorForward(turnSpeedPercent);
      miServo.write(SERVO_MAX_LEFT);

      if (millis() - turnStartTime >= turn90TimeMs) {
        finishTurnAndReturnToDrive();
      }

      break;
    }

    /* ===================================================
       STATE 3: TURNING RIGHT
       ---------------------------------------------------
       Keep steering fully right and moving forward until
       the programmed turning time is completed.
       =================================================== */
    case STATE_TURNING_RIGHT: {
      setMotorForward(turnSpeedPercent);
      miServo.write(SERVO_MAX_RIGHT);

      if (millis() - turnStartTime >= turn90TimeMs) {
        finishTurnAndReturnToDrive();
      }

      break;
    }

    /* ===================================================
       STATE 4: FINISHED
       ---------------------------------------------------
       Safety state: keep the robot stopped.
       =================================================== */
    case STATE_FINISHED: {
      stopMotor();
      miServo.write(SERVO_CENTER);
      break;
    }
  }
}

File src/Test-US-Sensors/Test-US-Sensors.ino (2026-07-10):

// Definición de Pines de Sensores US (HC-SR04)
#define TRIG1 8 // Sensor delantero
#define ECHO1 9
#define TRIG2 10 // Sensor Izquierdo
#define ECHO2 11
#define TRIG3 12 // Sensor Derecho
#define ECHO3 13

const unsigned long printInterval = 1000; // Intervalo de 5 segundos
unsigned long previousMillis = 0;

void setup() {
  Serial.begin(9600); // Iniciar la comunicación Serial

  // Configuración de pines de HC-SR04
  pinMode(TRIG1, OUTPUT);
  pinMode(ECHO1, INPUT);
  pinMode(TRIG2, OUTPUT);
  pinMode(ECHO2, INPUT);
  pinMode(TRIG3, OUTPUT);
  pinMode(ECHO3, INPUT);
}

void loop() {
  unsigned long currentMillis = millis();
  
  // Verificar si han pasado 5 segundos
  if (currentMillis - previousMillis >= printInterval) {
    previousMillis = currentMillis;
    
    // Obtener los valores de los sensores ultrasónicos y de color
    int distanceFront = measureDistance(TRIG1, ECHO1);
    int distanceLeft = measureDistance(TRIG2, ECHO2);
    int distanceRight = measureDistance(TRIG3, ECHO3);
    
    // Mostrar los valores en el Serial
    Serial.print("Distancia delantera: "); Serial.print(distanceFront); Serial.println(" cm");
    Serial.print("Distancia izquierda: "); Serial.print(distanceLeft); Serial.println(" cm");
    Serial.print("Distancia derecha: "); Serial.print(distanceRight); Serial.println(" cm");
    Serial.println("----------------------------");
  }
}

// Función para medir la distancia con los sensores ultrasónicos
int measureDistance(int trigPin, int echoPin) {
  digitalWrite(trigPin, LOW);
  delayMicroseconds(2);
  digitalWrite(trigPin, HIGH);
  delayMicroseconds(10);
  digitalWrite(trigPin, LOW);
  
  long duration = pulseIn(echoPin, HIGH);
  int distance = duration * 0.034 / 2;
  return distance;
}

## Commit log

2026-06-22 Primer github
    Se comenzaron a poner las bases de la documentación hasta los avances que habian hasta el momento.
2026-06-27 Enhance README with project details and structure
    Updated README.md with detailed folder structure, engineering materials, building instructions, competition overview, and strategy explanation.
2026-06-27 Revise README for improved organization and detail
    Updated README to enhance structure and clarity, including folder overview, engineering materials, building instructions, introduction, mobility, strategy, and power management sections.
2026-06-27 Add README for electrical and wiring diagrams
    This README file provides an overview of the electrical and wiring diagrams for the robot, detailing component connections and their importance for debugging and maintenance.
2026-06-27 Add README for robot mobility system
    Added detailed documentation about the robot's mobility system, including its steering and propulsion architecture.
2026-06-27 Rename README.md for servo motor directory
2026-06-27 Fix links in README for motors
    Updated links for DC Motor and Servo Motor sections to include a trailing slash.
2026-06-27 Motor Driver Photos
    Remove empty README.md file from motor-driver directory
2026-06-27 3d Models Files
    Added .stl files of every 3d printed part of the robot.
    [Camera mount.stl, Motor Mount.stl, Motor gear.stl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]
2026-06-27 Add temporary steering pic
2026-06-27 Add temporary battery pic
2026-06-27 Add temporary motor driver pics
2026-06-27 Add temporary ultrasonic sensors pics
2026-06-27 add temporary servo motor pic
2026-07-05 Change battery pack specification to 4S 18650
    Updated battery specifications from 3S to 4S 18650 lithium battery pack throughout the document.
2026-07-08 Replace Arduino Nano 33 IoT with Arduino Mega 2560 R3
    Updated references from Arduino Nano 33 IoT to Arduino Mega 2560 R3 throughout the document.
2026-07-10 Update battery case details and code explanation sections
    Clarified battery case configurations and outlined future algorithm development phases.
2026-07-10 Add arduino pics
2026-07-10 Add battery pics
2026-07-10 Add dc motor pics
2026-07-10 Add motor driver pic
2026-07-10 Add servo motor pic
2026-07-10 Add steering mechanism pics
2026-07-10 Correct engineering materials quantities in README
    Updated the quantity of proto wires and fuses in the engineering materials section.
2026-07-10 Add wiring explanation and hardware architecture
    Added detailed wiring explanation and hardware architecture for the robot, including power distribution, component connections, and electrical design notes.
2026-07-10 Schemes
    Added a section for detailed wiring explanation to enhance documentation clarity.
2026-07-14 Schemes
    Update battery configuration from 4-cell to 3-cell pack
2026-09-08 Enhance power management details in README
    Expanded the power management section to provide detailed information about the battery pack, L298N motor driver, and power distribution to various components. Added safety features regarding the mai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
2026-09-08 Expand README with detailed robot components information
    Added detailed sections on power system, main controller, vision system, ultrasonic sensors, drive system, motor driver, mechanical structure, wiring diagram, and component gallery.
2026-09-10 Update README with Arduino Mega 2560 R3 details
    Added a description of the Arduino Mega 2560 R3 and its role in the robot.
2026-09-10 Add battery pack information to README
    Added details about the battery pack specifications and connections.
2026-09-10 Update README with drive motor details
    Added a description of the drive motor and its features.
2026-09-10 Update README with L298N motor driver details
    Added introductory information about the L298N motor driver, including its functionality and benefits for robotics projects.
2026-09-10 Update README for Pixy2 Camera description
    Added introduction and functionality details for Pixy2 Camera.
2026-09-10 Update README with MG996R servo details
    Added detailed description of the MG996R steering servo.
2026-09-10 Electromechanical Components
    Added description of ultrasonic sensors and their functionality.
2026-09-10 Update README with rear-wheel drive system details
    Added an overview of the rear-wheel drive system used in the robot.
2026-09-10 Enhance README with Ackermann steering mechanism info
    Added details about the Ackermann steering mechanism and its benefits.
2026-09-10 Update README with building instructions
    Added a new section for building instructions with details on chassis, 3D models, electronics, and code.
2026-09-10 Update README to reflect Arduino Mega 2560 usage
2026-09-10 Update motor specifications and wiring details in README
2026-09-10 Update README with correct Arduino model and links
